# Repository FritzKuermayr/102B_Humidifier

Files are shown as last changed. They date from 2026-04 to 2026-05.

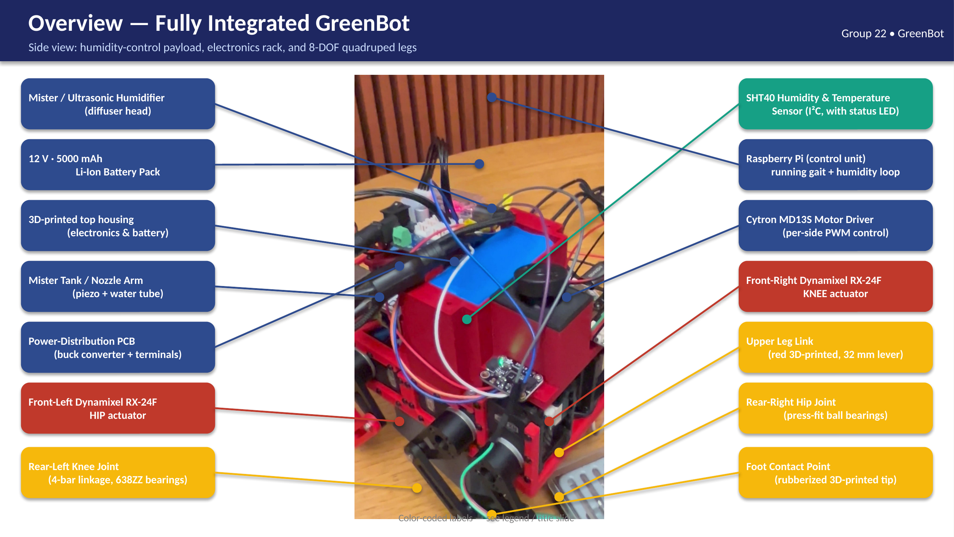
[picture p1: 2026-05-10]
docs/images/01_Overview.png

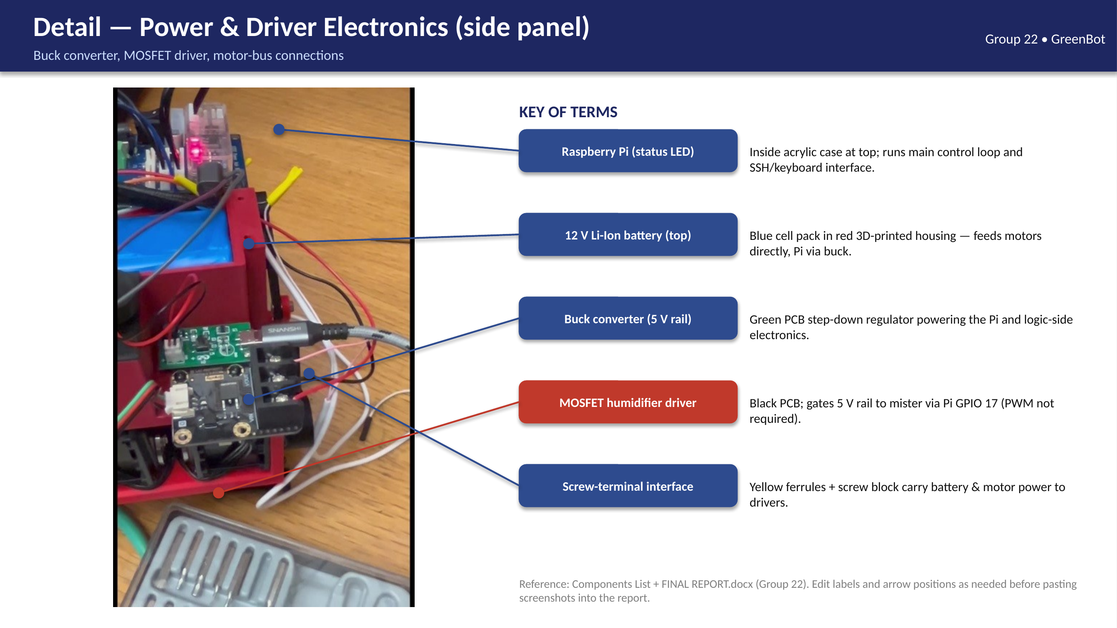
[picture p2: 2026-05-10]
docs/images/03_ElectronicsDetail.png

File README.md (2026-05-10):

# 102B — Quadruped + Humidity Control

This repository combines two subsystems used in the ME 102B project:

- **Quadruped controller** (Raspberry Pi, Dynamixel RX-24F) — keyboard-driven
  gait control over SSH.
- **Humidifier controller** (ESP32 + SHT40 + MOSFET) — closed-loop humidity
  control firmware and wiring docs.

A small set of shared Dynamixel utilities lives at the top level under
`tools/`. Course documents (reports, presentations, CAD, renders) are under
[`docs/`](docs/) — see [`docs/README.md`](docs/README.md).

## Repository Layout

```text
.
├── README.md
├── docs/                            # Reports, presentations, CAD, renders
├── software/
│   ├── humidifier/                  # ESP32 humidity control firmware + wiring
│   │   ├── esp32_humidity_control/
│   │   ├── esp32_humidity_control_switch/
│   │   ├── esp32_mosfet_test/
│   │   ├── esp32_sht40_test/
│   │   ├── wiring_humidity_control.md
│   │   └── wiring_humidity_control_switch.md
│   └── quadruped/                   # Raspberry Pi gait control
│       ├── raspi_controller/
│       │   ├── main.py
│       │   ├── g_key_leg_test.py
│       │   ├── keyboard_interface.py
│       │   └── q8gait/
│       ├── dynamixel_tools/         # Optional C utilities (DynamixelSDK)
│       ├── requirements.txt
│       └── setup_pi.sh
└── tools/                           # Standalone Dynamixel test scripts
    ├── dynamixel_scan.py
    └── single_motor_test.py
```

---

## Humidifier (ESP32)

Arduino sketches for a humidity controller using an SHT40 sensor and a
MOSFET-switched humidifier output. Open the `.ino` files with the Arduino
IDE / arduino-cli.

- `software/humidifier/esp32_humidity_control/` — closed-loop control
- `software/humidifier/esp32_humidity_control_switch/` — switch-driven variant
- `software/humidifier/esp32_mosfet_test/` — MOSFET output bring-up
- `software/humidifier/esp32_sht40_test/` — SHT40 sensor bring-up

Wiring is documented in
[`software/humidifier/wiring_humidity_control.md`](software/humidifier/wiring_humidity_control.md)
and
[`software/humidifier/wiring_humidity_control_switch.md`](software/humidifier/wiring_humidity_control_switch.md).

---

## Quadruped (Raspberry Pi)

Keyboard-driven control software for the quadruped, run directly on the Pi
over SSH.

- Pi and laptop on the same Wi-Fi network (no hotspot).
- Code on the Pi in `~/102B_Humidifier`.
- Movement: `h/j/k/l` (arrow keys as fallback).
- Default Dynamixel port `/dev/ttyUSB0`, baudrate `1000000`.
- Motors: Dynamixel RX-24F, protocol `1.0`.

### Prepare the Raspberry Pi

1. Flash Raspberry Pi OS to the microSD card.
2. Enable SSH during flashing or afterwards.
3. Connect the Pi to the regular Wi-Fi network.
4. Find the Pi's IP address: `hostname -I` — or `ssh pi@raspberrypi.local`.

### Install on the Pi

```bash
cd ~
git clone https://github.com/FritzKuermayr/102B_Humidifier.git
cd ~/102B_Humidifier
chmod +x software/quadruped/setup_pi.sh
./software/quadruped/setup_pi.sh
```

Update an existing checkout:

```bash
cd ~/102B_Humidifier
git pull origin main
```

Plug in the Dynamixel USB adapter and check it:

```bash
ls /dev/ttyUSB* /dev/ttyACM*
sudo chmod a+rw /dev/ttyUSB0   # if needed
```

### Python Dependencies

`software/quadruped/setup_pi.sh` handles installation. To reinstall:

```bash
cd ~/102B_Humidifier
source .venv/bin/activate
python -m pip install -r software/quadruped/requirements.txt
```

### Start Keyboard Control

Place the robot on a stand for the first test.

```bash
cd ~/102B_Humidifier
source .venv/bin/activate
python software/quadruped/raspi_controller/main.py \
    --port /dev/ttyUSB0 --gait TROT_LOW --torque-limit 400
```

Keys:

```text
k      walk forward
j      walk backward
h      turn left
l      turn right
Space  stop and hold neutral stance
s      stop and hold neutral stance
q      quit safely and disable torque
```

Arrow keys also work if the terminal passes them through:

```text
↑  forward    ↓  backward    ←  turn left    →  turn right
```

If the motors react too weakly on the stand, increase the torque limit:

```bash
python software/quadruped/raspi_controller/main.py \
    --port /dev/ttyUSB0 --gait TROT_LOW --torque-limit 500
```

Alternative gaits:

```bash
python software/quadruped/raspi_controller/main.py --port /dev/ttyUSB0 --gait WALK --torque-limit 500
python software/quadruped/raspi_controller/main.py --port /dev/ttyUSB0 --gait TROT --torque-limit 500
```

### Single-Leg Test

Moves only the front-left leg slightly away from neutral and back. For motor
and mapping checks only.

```bash
cd ~/102B_Humidifier
source .venv/bin/activate
python software/quadruped/raspi_controller/g_key_leg_test.py --port /dev/ttyUSB0
```

Keys: `g` to twitch the front-left leg, `q` to quit.

Mapping:

```text
FL_q1 = Motor ID 1
Neutral = 150 deg
Test movement = 165 deg for 0.35 s, then back to 150 deg
```

### Important Checks

- Motor IDs and ordering: [`software/quadruped/raspi_controller/q8gait/config_rx24f.py`](software/quadruped/raspi_controller/q8gait/config_rx24f.py).
- On startup, `main.py` moves all motors to neutral.
- On exit (`q` or `Ctrl+C`) torque is disabled.
- Always put the robot on a stand before the first motion test.
- Missing `dynamixel_sdk`: `python -m pip install -r software/quadruped/requirements.txt`.
- `/dev/ttyUSB0` not accessible: check the USB adapter, run
  `sudo chmod a+rw /dev/ttyUSB0`.

---

## Standalone Dynamixel Tools

Quick utilities under `tools/`:

- [`tools/dynamixel_scan.py`](tools/dynamixel_scan.py) — scan the bus for connected motors.
- [`tools/single_motor_test.py`](tools/single_motor_test.py) — gentle wobble test for a single motor.

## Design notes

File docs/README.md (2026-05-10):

# Project Documents — ME 102B Team 22

Course documents, reports, presentations, CAD, and renders for the ME 102B
Greenhouse-Bot project.

Videos (`.MOV`, `.mp4`) are excluded — they exceed GitHub's 100 MB per-file
limit. They live locally in the team archive.

## Contents

### `reports/`
- `FINAL REPORT me102b greenhousebot.docx` — final written report
- `FINAL_REPORT_with_labels.docx` — final report with labeled figures
- `P1 and P2 Assignment.docx` — P1/P2 assignment write-up
- `P1P2 Completed Merged.pdf` — merged P1+P2 submission
- `P3.docx` — P3 write-up
- `p4b.docx` — P4b write-up
- `P5.docx` — P5 write-up
- `cartoon (if needed again).docx` — optional cartoon storyboard

### `presentations/`
- `P1P2 PPT ME102B.pptx` — P1/P2 deck
- `P4 PPT ME102B.pptx` — P4 deck
- `GreenBot_Labeled.pptx` — labeled GreenBot deck
- `P1-P2-Teaming-And-Pitch.pdf` — teaming/pitch reference

### `diagrams/`
- `FINAL_StateDiagrams.pdf` — final state diagrams

### `cad/`
Mechanical CAD (STL for printing, STEP/STP for editing):
- `Battery-Holder.stp`
- `Controller_Holder.stl` / `.stp`
- `ESP platform.stl` / `.step`
- `Lid.stl` / `.step` and `Lidv8.stl`
- `Motor_37D.stl`
- `Upper_part.stp`

### `images/`
Labeled renders of the final assembly:
- `00_Title.png` — title image
- `01_Overview.png` — full overview
- `02_TopDetail.png` — top-side detail
- `03_ElectronicsDetail.png` — electronics detail

### `misc/`
- `102 B Team 22 Pugh Matrix.xlsx` — Pugh matrix
- `Components List.docx` — bill of materials / parts list

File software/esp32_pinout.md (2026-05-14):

# ESP32 Feather V2 — Pin Connections

Compact reference: which Feather pin connects to what. No wire colors —
those are in [`wiring_map_esp32.md`](wiring_map_esp32.md) and the
per-sketch wiring docs.

## Connections

| Feather V2 pin | Connected to |
|---|---|
| `3V` | MOSFET VCC, SHT40 VCC |
| `GND` (left) | MOSFET GND, Switch GND* |
| `GND` (right) | SHT40 GND |
| `27` | MOSFET SIG |
| `33` | Switch input* |
| `SDA` (= GPIO22)  | SHT40 SDA |
| `SCL` (= GPIO20)  | SHT40 SCL |

\* Only used by `esp32_humidity_control_switch.ino`. Switch GND shares
the same physical `GND (left)` pin as the MOSFET GND.

## External supply for the mister

Independent from the Feather; only the MOSFET output drives the mister.

| External rail | Connected to |
|---|---|
| Supply +V | MOSFET VIN (screw terminal) |
| Supply GND | MOSFET GND (screw terminal), Feather GND  |
| MOSFET VOUT | Mister + |
| Supply GND | Mister − |

The external supply GND **must** be tied to the Feather GND or the
MOSFET gate driver will not have a stable reference.

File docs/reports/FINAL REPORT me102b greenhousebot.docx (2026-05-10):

Final Report/ Manual
Group 22
Team Members: Bader AlKhawashki, Fritz Kuermayr, Salvador Gonzalez, Arunima Basu

Compile a “Manual” for your fully integrated device, such that another engineer could replicate, and even iterate upon, your project.

Opportunity:

For farmers/gardeners who own greenhouses, it’s a robot that detects local humidity within a greenhouse, and if it falls below a certain threshold (detected using analog and digital sensors), the robot humidifies the area using water mist and moves around the greenhouse to ensure proper humidification of the entire area.

High-level strategy:
Our GreenBot continuously monitors key greenhouse humidity conditions. When values drift outside target ranges, it automatically triggers the correct response (humidification).

Discussion of Initial and achieved specifications:

Discuss/compare your initial desired functionality to your achieved

specifications (e.g., we wanted to drive at least 1 foot per second and achieved a maximum speed

of 0.95 feet per second).

- A photo showing the integrated physical device, fully assembled and with labels showing where

actuators and sensors are located and highlighting any moving parts/joints. You can include a

couple views to show key subsystems as needed. Think of this diagram as a “key” of terms that

you can use in your description (e.g., “the wheel transmission...” highlight in the image what this

means to you).

Discussion of function-critical decisions and calculations.

1. Mass and Load Estimations

The total mass of the quadruped robot is estimated at approximately 2 kg, which is derived

from the main components. The eight Dynamixel RX-24F actuators contribute roughly 0.66

kg. The Raspberry Pi, OpenBCI Cyton board, and other electronics add about 0.1 kg,

and the 12 V 5000 mAh battery weighs approximately 0.35 kg. The structural components,

including the 3D-printed chassis and legs, are estimated at 0.5 kg, while the active water

payload adds about 0.3 kg.

Consequently, the total weight force acting on the robot’s center of mass is approximately

20 N. During locomotion, it is assumed as a worst-case scenario that only two legs support

the entire weight of the robot during parts of the gait cycle. Therefore, a single active leg

must support roughly 10 N of vertical static load.

2. Actuator Torque Analysis

The worst-case mechanical stress on the transmission occurs when the leg is fully extended

outward. This configuration creates the largest lever arm relative to the motor axis.

• Lever Arm: The leg length is 32 mm (0.032 m).

• Maximum Torque: The 10 N vertical load produces a resultant worst-case torque

at the motor of roughly 0.31 Nm.

The Dynamixel RX-24F actuator specified for the joints possesses a maximum stall torque

of approximately 2.6 Nm at 12 V. Because the estimated required torque of 0.31 Nm is

significantly lower than the maximum capability of the actuator, the design features a large

safety margin.

3. Bearing Load Standards (ABMA)

The primary load on the robot leg acts through the structure as a lever, transmitting forces

directly into the joints and bearings. The leg assembly utilizes 16 press-fit ball bearings to

support the rotational joints.

To verify the reliability of the transmission, the bearing loads were evaluated using American Bearing Manufacturers Association (ABMA) standards for deep-groove ball bearings.

The ABMA standard defines the effective combined bearing load using the following relationship:

Fe = (Xi· V · Fr) + (Yi· Fa)

Where:

• Fr is the radial load acting on the bearing

• Fa is the axial load

• V is a rotation factor (V = 1 when the inner ring rotates)

• Xi and Yi are radial and thrust load factors defined by the ABMA standard

In this design, the planar linkage introduces negligible axial load, therefore:

Fa = 0

The static load on a single leg is approximately 10 N. To account for dynamic walking

impacts and shocks, a conservative dynamic factor of 3 is applied. This results in a maximum

radial load of:

Fr = 30 N

Because Fa/C0 is below the ABMA limit value e, the standard coefficients are:

• Xi = 1.00

• Yi = 0

Substituting into the ABMA equation:

Fe = (1.00 · 1 · 30 N) + (0 · 0)

Fe = 30 N

Therefore, the effective bearing load is approximately 30 N in the worst-case dynamic

condition where all force is assumed to act on a single bearing.

This value remains significantly lower than the rated load capacity of standard miniature

deep-groove ball bearings such as the 638ZZ, confirming that the bearing operates safely

within its mechanical limits according to ABMA guidelines.

4. 3D-Printed Housing Tolerance Standards (ANSI)

The 16 ball bearings must be press-fit into the 3D-printed plastic upper and lower legs.

To achieve proper alignment without compromising the structural integrity of the additive

manufacturing layers, the interface relies on American National Standards Institute (ANSI)

limits and fits.

The theoretical CAD geometry was established around an ANSI H7/k6 locational transition fit. This standardized fit is an ideal compromise between clearance and interference

for accurate location.

However, standard locational interference fits (such as H7/p6) are designed for rigid

steel components and would cause the 3D-printed plastic to yield or delaminate under high

internal bore pressure. Therefore, the upper and lower fundamental deviations of the H7/k6

specification were adopted as a baseline, but light physical dimensional offsets were applied

during slicing to compensate for polymer creep and FDM resolution, ensuring a secure fit

that adheres to ANSI principles adapted for plastic housings.

State Diagrams:

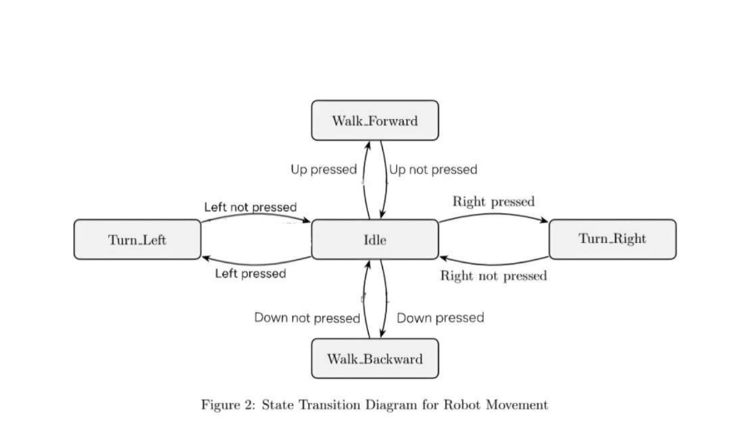
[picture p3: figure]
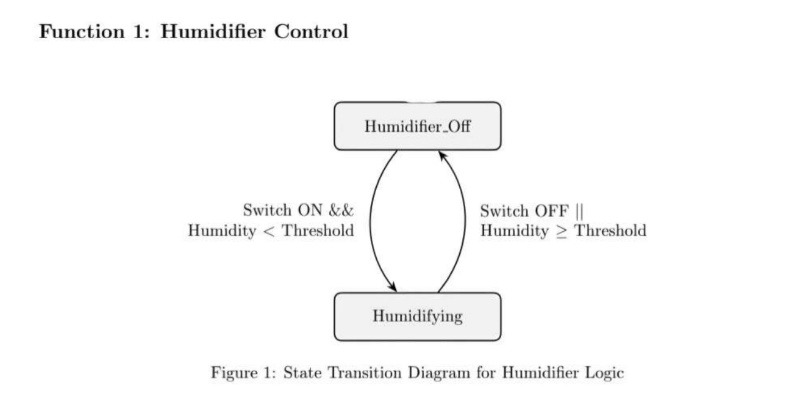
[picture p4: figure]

Reflection:
We recommend students buy spare parts in case of any issues, as one of our electronic parts had short-circuited; thankfully, we were able to fix the issue quickly using soldering, and all project deliverables were completed.

APPENDIX

o Complete Bill of Materials:

Section | Item | Qty | Cost/part (USD) | Subtotal
Upper Part | Humidity sensor | 1 | $0 | $0
Upper Part | Microcontroller (ESP32 Feather V2) | 1 | $0 | $0
Upper Part | Mister (pump + nozzle) | 1 | $10 | 10
Upper Part | Cables | 30 | $0 | $0
Upper Part | 3D-Printed Tank + Platform | 1 | $2 | $2
Upper Part | 3D Printed LED | 1 | $1 | $1
Lower Part | Upper legs (3D-printed) | 8 | $0.5 | $4
Lower Part | Lower legs (3D-printed) | 8 | $0.5 | $4
Lower Part | Ball bearings | 16 | $15 | $15
Lower Part | Chassis (3D-printed) | 1 | $5 | $5
Lower Part | Distance holder M2.5 (20 mm) | 6 | $0.15 | $1
Lower Part | Distance holder M2.5 (10 mm) | 6 | $0.15 | $1
Lower Part | Upper chassis (3-part print) | 1 | $2 | $2
Lower Part | Battery holder (3D-printed) | 1 | $1 | $1
Lower Part | Motor controller holder (3D-printed) | 1 | $1 | $1
Lower Part | Dynamixel RX-24F actuators | 8 | $0 | $0
Lower Part | 12V 5000mAh battery | 2 | $30 | $60
Lower Part | Raspberry Pi 4 | 1 | $75 | $75
Lower Part | Roboteck K4P | 9 | $20 | $180
Lower Part | USB-C to USB-B cable | 1 | $5 | $5
Lower Part | Diatone Mamba Micro 2A BEC | 1 | $4 | $4
Lower Part | U2D2 (USB-to-Serial) | 1 | $35 | $35
Lower Part | Arduino USB dongle | 1 | $10 | $10
Lower Part | Screws & Nuts | 20 | $5 | $5
Upper part | Washers | 10 | $5 | $5
Upper part | Fasteners | 10 | $0 | $0
Upper part | Gaskets | 10 | $0.5 | $5
Upper part | MOSFET | 1 | $15 | $15

o Images of the CAD, showing mechanical transmission elements.

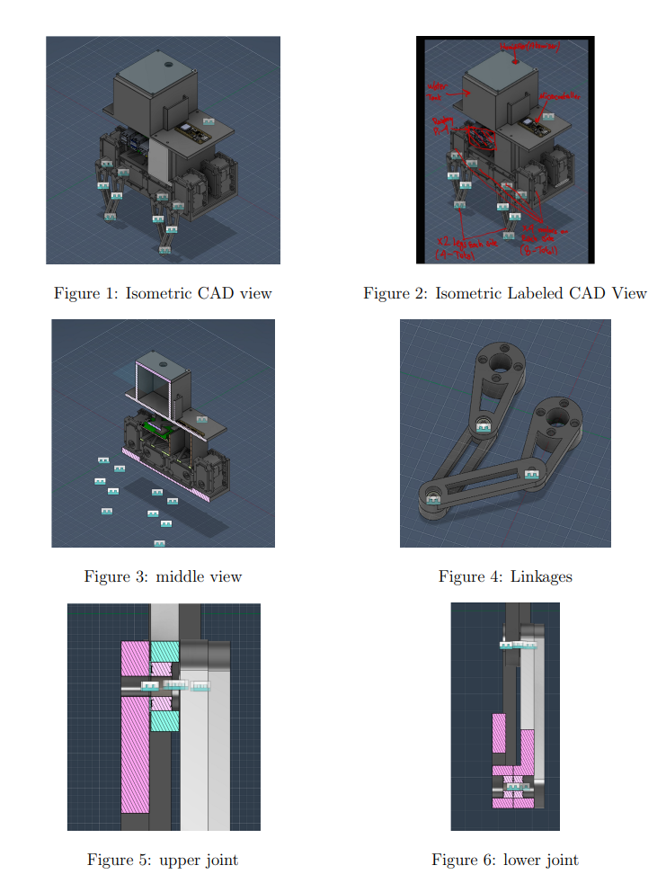
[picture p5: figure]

o Screen shots of your entire code, showing your event-driven program (most updated.)

Humidity Control Code:

1 from __future__ import annotations

2

3 import threading

4 import time

5 from dataclasses import dataclass

6 from typing import Optional

7

8 # Standard humidity - control c on fi gu ra ti on .

9 HUMIDITY_THRESHOLD = 45.0

10 SENSOR_POLL_INTERVAL_SEC = 2.0

11 HUMIDIFIER_GPIO = 17

12 ENABLE_SWITCH_GPIO = 27

13 I2C_SENSOR = " SHT40 on Raspberry Pi I2C1 : GPIO2 / SDA1 and GPIO3 / SCL1 "

14 SWITCH_DEBOUNCE_MS = 50

15

16

17 @dataclass ( frozen = True )

18 class HumidityControlConfig :

19 humidity_threshold : float = HUMIDITY_THRESHOLD

20 sensor_poll_interval_sec : float = SENSOR_POLL_INTERVAL_SEC

21 humidifier_gpio : int = HUMIDIFIER_GPIO

22 enable_switch_gpio : int = ENABLE_SWITCH_GPIO

23 switch_debounce_ms : int = SWITCH_DEBOUNCE_MS

24

25

26 class HumidityController :

27 """

28 Non - blocking SHT40 humidity controller for a MOSFET - switched humidifier .

29

30 The control loop runs in its own daemon thread . Any sensor read error or

31 disabled enable switch forces the humidifier GPIO low .

32 """

33

34 def __init__ ( self , config : Optional [ HumidityControlConfig ] = None ) -> None :

35 self . config = config or HumidityControlConfig ()

36 self . _stop_event = threading . Event ()

37 self . _thread : Optional [ threading . Thread ] = None

38 self . _humidifier_output = None

39 self . _enable_switch = None

40 self . _sensor = None

41

42 def start ( self ) -> None :

43 if self . _thread is not None :

44 return

45

46 try :

47 self . _setup_gpio ()

48 self . _humidifier_off ()

49 except Exception :

50 self . _humidifier_off ()

51 self . _close_gpio ()

52 raise

53

54 self . _thread = threading . Thread (

55 target = self . _loop , name =" humidity - control ", daemon = True

56 )

57 self . _thread . start ()

58 print (

59 "[ humidity ] started "

60 f" threshold ={ self . config . humidity_threshold :.1 f}% "

61 f" poll ={ self . config . sensor_poll_interval_sec :.1 f}s"

62 )

63

64 def stop ( self ) -> None :

65 self . _stop_event . set ()

66 if self . _thread is not None :

67 self . _thread . join (

68 timeout = max (1.0 , self . config . sensor_poll_interval_sec + 0.5)

69 )

70 self . _thread = None

71

72 self . _humidifier_off ()

73 self . _close_gpio ()

74 print ("[ humidity ] stopped ")

75

76 # STATE MACHINE DRIVER :

77 # Periodically runs the humidity - control state machine without blocking the

78 # quadruped movement loop .

79 def _loop ( self ) -> None :

80 while not self . _stop_event . is_set () :

81 self . _control_once ()

82 self . _stop_event . wait ( self . config . sensor_poll_interval_sec )

83

84 # STATE MACHINE TRANSITION LOGIC :

85 def _control_once ( self ) -> None :

86 if not self . _switch_enabled () :

87 self . _humidifier_off ()

88 return

89

90 humidity = self . _read_humidity ()

91 if humidity is None :

92 self . _humidifier_off ()

93 return

94

95 if humidity < self . config . humidity_threshold :

96 self . _humidifier_on ()

97 else :

98 self . _humidifier_off ()

99

100 # SERVICE FUNCTION :

101 def _setup_gpio ( self ) -> None :

102 try :

103 from gpiozero import Button , DigitalOutputDevice

104 except ImportError as exc :

105 raise RuntimeError (

106 " gpiozero is required for humidity control . Run software / setup_pi .sh on the Raspberry

Pi."

107 ) from exc

108

109 self . _humidifier_output = DigitalOutputDevice (

110 self . config . humidifier_gpio ,

111 active_high = True ,

112 initial_value = False ,

113 )

114 self . _enable_switch = Button (

115 self . config . enable_switch_gpio ,

116 pull_up = True ,

117 bounce_time = self . config . switch_debounce_ms / 1000.0 ,

118 )

119

120 # SERVICE FUNCTION :

121 def _close_gpio ( self ) -> None :

122 for device in ( self . _humidifier_output , self . _enable_switch ):

123 if device is not None :

124 device . close ()

125 self . _humidifier_output = None

126 self . _enable_switch = None

127

128 # EVENT CHECKER :

129 def _switch_enabled ( self ) -> bool :

130 return bool ( self . _enable_switch is not None and self . _enable_switch . is_pressed )

131

132 # SERVICE FUNCTION :

133 def _humidifier_on ( self ) -> None :

134 if self . _humidifier_output is not None :

135 self . _humidifier_output . on ()

136

137 # SERVICE FUNCTION :

138 def _humidifier_off ( self ) -> None :

139 if self . _humidifier_output is not None :

140 self . _humidifier_output . off ()

141

142 # EVENT CHECKER :

143 def _read_humidity ( self ) -> Optional [ float ]:

144 sensor = self . _get_sensor ()

145 if sensor is None :

146 return None

147

148 try :

149 _temperature_c , relative_humidity = sensor . measurements

150 except Exception as exc :

151 print (f"[ humidity ] sensor read failed ; humidifier off : { exc}")

152 self . _sensor = None

153 return None

154

155 return float ( relative_humidity )

156

157 # SERVICE FUNCTION :

158 def _get_sensor ( self ):

159 if self . _sensor is not None :

160 return self . _sensor

161

162 try :

163 import adafruit_sht4x

164 import board

165

166 self . _sensor = adafruit_sht4x . SHT4x ( board . I2C () )

167 except Exception as exc :

168 print (f"[ humidity ] sensor init failed ; humidifier off : { exc}")

169 self . _sensor = None

170

171 return self . _sensor

Motion Control Code:
1 from __future__ import annotations

2

3 import time

4 from typing import Optional

5

6 from . gait_manager import GAITS , GaitManager

7 from . kinematics_solver import k_solver

8 from . robot import Robot

9

10 COMMAND_TO_DIRECTION = {

11 # MOVEMENT STATE MACHINE STATES :

12 # " stop " is the IDLE state . The other commands are active movement states .

13 " forward ": "f",

14 " backward ": "b",

15 " turn_left ": "l",

16 " turn_right ": "r",

17 " stop ": None ,

18 }

19

20

21 class MotionRunner :

22 def __init__ (

23 self ,

24 robot : Robot ,

25 leg_solver : k_solver ,

26 gait_name : str = " TROT_LOW ",

27 hz : int = 50 ,

28 neutral_center_deg : float = 150.0 ,

29 torque_limit : int = 600 ,

30 moving_speed : int = 0,

31 ) -> None :

32 self . robot = robot

33 self . leg = leg_solver

34 self . hz = hz

35 self . dt = 1.0 / hz

36 self . neutral_center_deg = neutral_center_deg

37 self . torque_limit = torque_limit

38 self . moving_speed = moving_speed

39 self . gait_manager = GaitManager ( self . leg , GAITS )

40 self . current_command = " stop "

41

42 if not self . gait_manager . load_gait ( gait_name ):

43 raise RuntimeError (f" Failed to load gait { gait_name }")

44

45 _ , x0 , y0 , *_ = GAITS [ gait_name ]

46 q1n , q2n , ok = self . leg . ik_solve (x0 , y0 , True , 3)

47 if not ok :

48 raise RuntimeError ("IK failed for neutral pose .")

49 self . q_neutral = [ q1n , q2n , q1n , q2n , q1n , q2n , q1n , q2n ]

50

51 # SERVICE FUNCTION :

52 def move_to_neutral ( self , seconds : float = 1.0) -> None :

53 command = [ self . neutral_center_deg ] * 8

54 for _ in range (max (1 , int ( seconds * self . hz ))):

55 self . robot . write_positions_deg ( command )

56 time . sleep ( self . dt )

57

58 # STATE MACHINE TRANSITION LOGIC :

59 def set_command ( self , command : Optional [ str ]) -> None :

60 if command is None or command == self . current_command :

61 return

62

63 if command == " quit ":

64 raise KeyboardInterrupt

65

66 direction = COMMAND_TO_DIRECTION . get ( command )

67 if direction is None :

68 self . gait_manager . stop ()

69 self . current_command = " stop "

70 return

71

72 self . robot . set_torque_limit_all ( self . torque_limit )

73 self . robot . set_moving_speed_all ( self . moving_speed )

74

75 if not self . gait_manager . start_movement ( direction ):

76 self . gait_manager . stop ()

77 self . current_command = " stop "

78 return

79

80 self . current_command = command

81

82 # SERVICE FUNCTION :

83 def tick ( self ) -> None :

84 q_abs = self . gait_manager . tick ()

85 if q_abs is None :

86 self . robot . write_positions_deg ([ self . neutral_center_deg ] * 8)

87 return

88

89 self . robot . write_positions_deg ( self . _recenter_to_neutral ( q_abs ))

90

91 # STATE MACHINE DRIVER :

92 def loop_forever ( self , keyboard_interface ) -> None :

93 next_tick = time . perf_counter ()

94 while True :

95 self . set_command ( keyboard_interface . poll () )

96

97 now = time . perf_counter ()

98 if now >= next_tick :

99 self . tick ()

100 next_tick += self . dt

101 else :

102 time . sleep ( max (0.0 , next_tick - now ))

103

104 # SERVICE FUNCTION :

105 def _recenter_to_neutral ( self , q_abs_8 : list [ float ]) -> list [ float ]:

106 return [

107 self . neutral_center_deg + ( q_abs_8 [i] - self . q_neutral [i ])

108 for i in range (8)

109 ]

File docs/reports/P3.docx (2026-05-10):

Deliverable 1: Isometric screen shot of your design with labels for understanding, and any sub-

assembly close-ups or cross-sections to show how it works should also be included as needed.

Components List:
Upper Part:

- Humidity sensor - https://projecthub.arduino.cc/rudraksh2008/temperature-and-humidity-sensor-with-arduino-1d52a6
- Microcontroller .- Adafruit V2 ESP 32 - https://github.com/adafruit/Adafruit_CAD_Parts/tree/main/5400%20ESP32%20Feather%20V2
- Mister (https://www.amazon.com/MTDELE-Humidifier-Atomization-Compatible-Incubation/dp/B0DC73SF6L?nsdOptOutParam=true) - Pump mechanism + nozzle - (Ordered)
- Cables
- 3D-Printed Tank + Platform
- 3D Printed led

Lower Part:

- 8× upper leg (3D-printed)
- 8× lower leg (3D-printed)
- 16× ball bearings (press-fit)
- 1× chassis (3D-printed)
- 6× distance holder, M2.5, 20 mm (3D-printed)
- 6× distance holder, M2.5, 10 mm (3D-printed)
- 1× upper chassis (3D-printed, 3-part print)
- 1× battery holder (3D-printed)
- 1× motor controller holder (3D-printed)
- 8× Dynamixel RX-24F robot actuators
- 1× 12 V 5000 mAh battery
- 1× Raspberry Pi 4
- 9× Roboteck K4P
- 1× USB-C to USB-B cable
- 1× Diatone Mamba Micro 2A BEC
- 1× U2D2 (USB-to-Serial)
- 1× Arduino USB dongle

Screws & Nuts

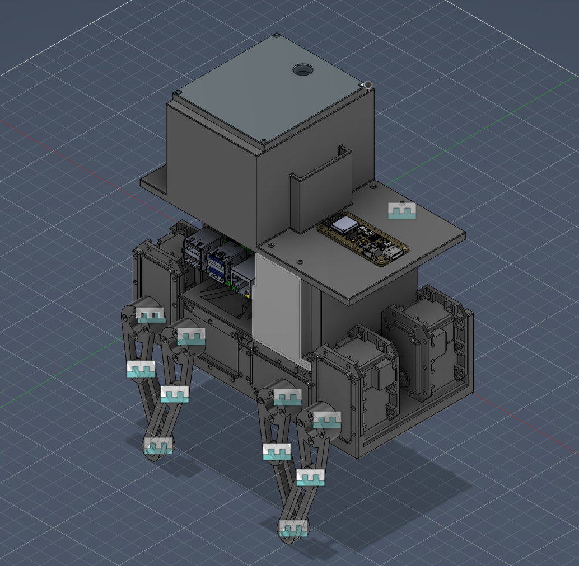
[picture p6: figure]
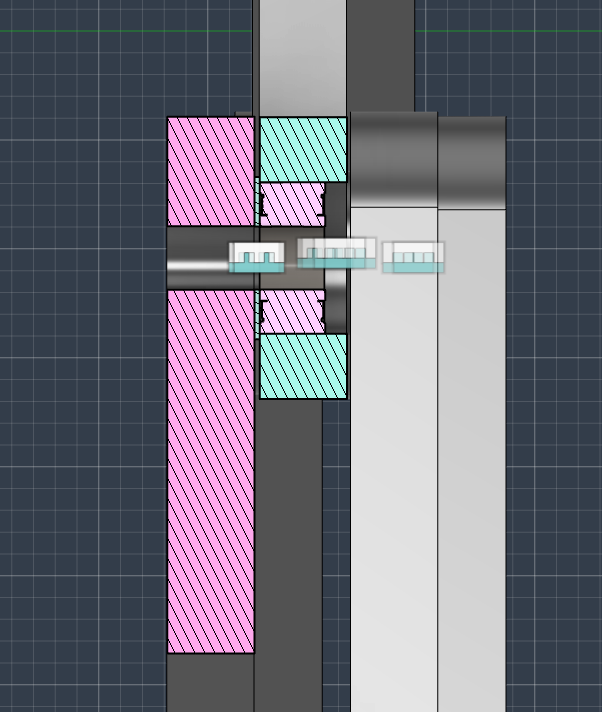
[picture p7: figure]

Upper Joint

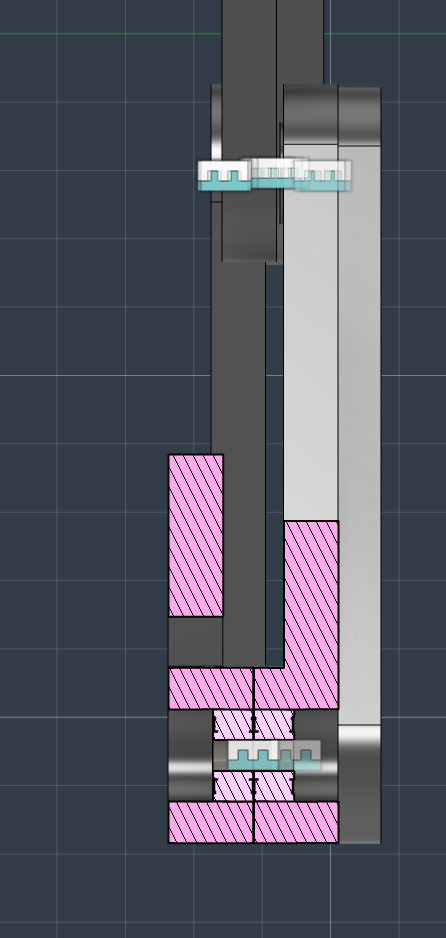
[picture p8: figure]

Lower joint

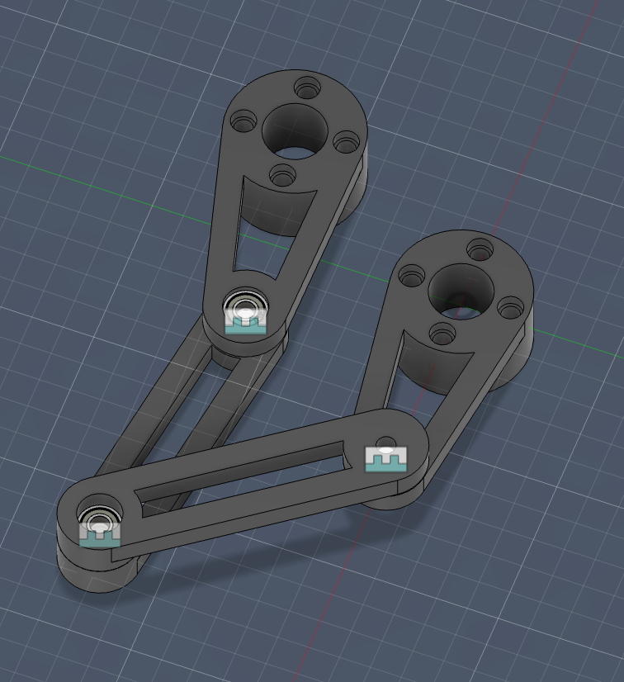
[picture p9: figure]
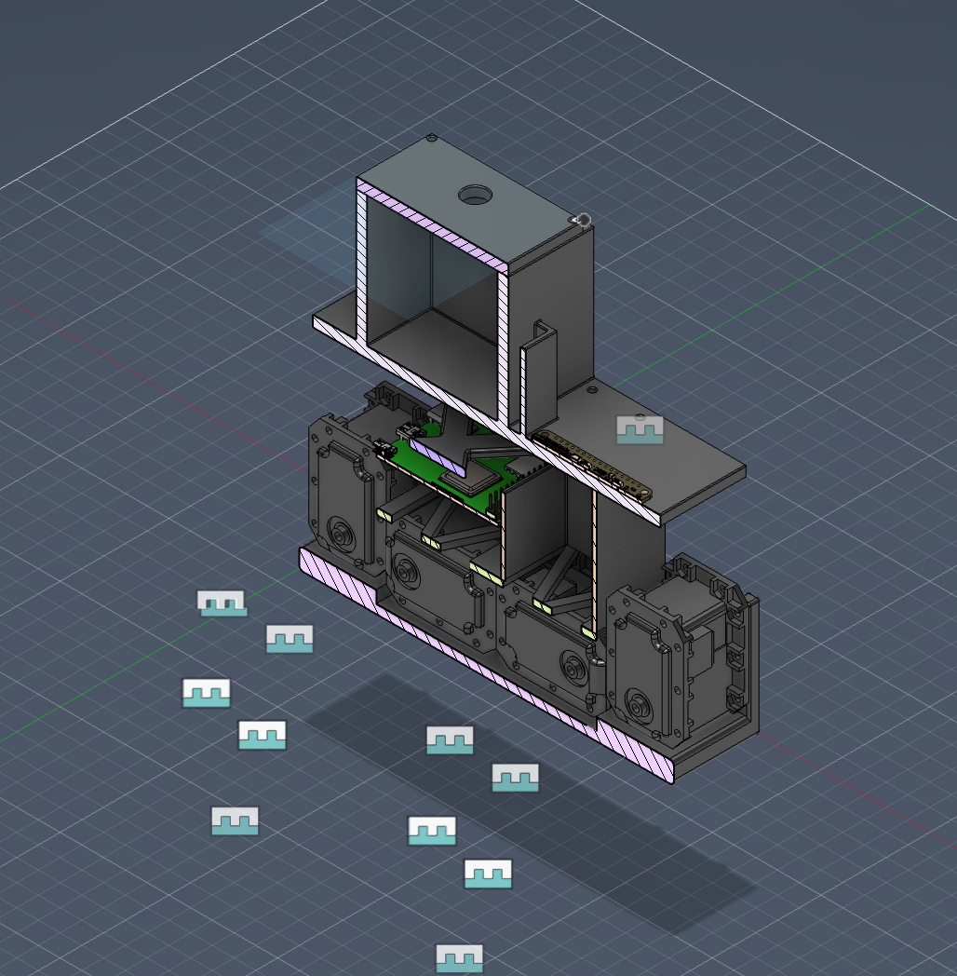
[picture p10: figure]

Cross sectional views

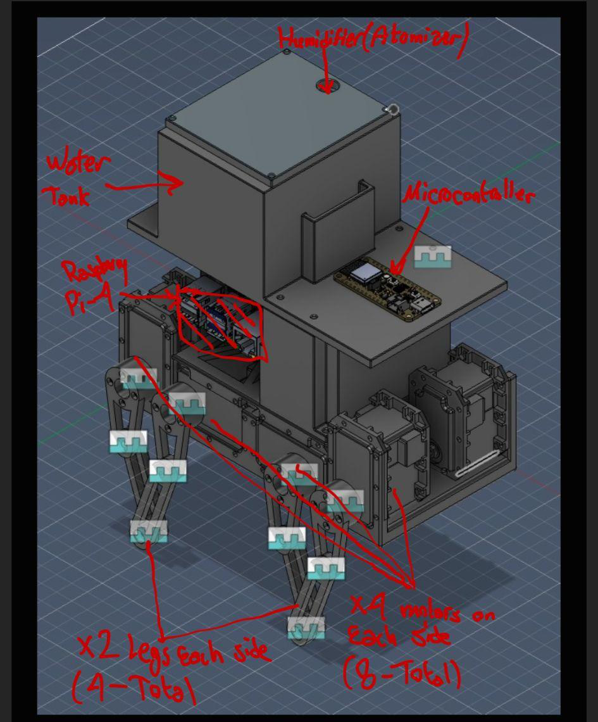
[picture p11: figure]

V2 Response

Deliverable 2: Function-Critical Calculations & Standards Integration

1. Mass and Load Estimations

The total mass of the quadruped robot is estimated at approximately 2 kg, which is derived from the main components. The eight Dynamixel RX-24F actuators contribute roughly 0.66 kg. The Raspberry Pi, OpenBCI Cyton board, and other electronics add about 0.1 kg, and the 12 V 5000 mAh battery weighs approximately 0.35 kg. The structural components, including the 3D-printed chassis and legs, are estimated at 0.5 kg, while the active water payload adds about 0.3 kg.

Consequently, the total weight force acting on the robot's center of mass is approximately 20 N. During locomotion, it is assumed as a worst-case scenario that only two legs support the entire weight of the robot during parts of the gait cycle. Therefore, a single active leg must support roughly 10 N of vertical static load.

2. Actuator Torque Analysis

The worst-case mechanical stress on the transmission occurs when the leg is fully extended outward. This configuration creates the largest lever arm relative to the motor axis.

- Lever Arm: The leg length is 32 mm (0.032 m).
- Maximum Torque: The 10 N vertical load produces a resultant worst-case torque at the motor of roughly 0.31 Nm.

The Dynamixel RX-24F actuator specified for the joints possesses a maximum stall torque of approximately 2.6 Nm at 12 V. Because the estimated required torque of 0.31 Nm is significantly lower than the maximum capability of the actuator, the design features a large safety margin.

## 3.Bearing Load Standards (ABMA)

The primary load on the robot leg acts through the structure as a lever, transmitting forces directly into the joints and bearings. The leg assembly utilizes 16 press-fit ball bearings to support the rotational joints.

To verify the reliability of the transmission, the bearing loads were evaluated using American Bearing Manufacturers Association (ABMA) standards for deep-groove ball bearings. The ABMA standard defines the effective combined bearing load using the following relationship:

Fe = (Xi · V · Fr) + (Yi · Fa)

Where:

- Fr is the radial load acting on the bearing
- Fa is the axial load
- V is a rotation factor (V = 1 when the inner ring rotates)
- Xi and Yi are radial and thrust load factors defined by the ABMA standard

In this design, the planar linkage introduces negligible axial load, therefore:

Fa = 0

The static load on a single leg is approximately 10 N. To account for dynamic walking impacts and shocks, a conservative dynamic factor of 3 is applied. This results in a maximum radial load of:

Fr = 30 N

Because Fa / C0 is below the ABMA limit value e, the standard coefficients are:

Xi = 1.00
Yi = 0

Substituting into the ABMA equation:

Fe = (1.00 · 1 · 30 N) + (0 · 0)

Fe = 30 N

Therefore, the effective bearing load is approximately 30 N in the worst-case dynamic condition where all force is assumed to act on a single bearing.

This value remains significantly lower than the rated load capacity of standard miniature deep-groove ball bearings such as the 638ZZ, confirming that the bearing operates safely within its mechanical limits according to ABMA guidelines.

Standards and Codes_v2 (1)

4. 3D-Printed Housing Tolerance Standards (ANSI)

The 16 ball bearings must be press-fit into the 3D-printed plastic upper and lower legs. To achieve proper alignment without compromising the structural integrity of the additive manufacturing layers, the interface relies on American National Standards Institute (ANSI) limits and fits.

The theoretical CAD geometry was established around an ANSI H7/k6 locational transition fit. This standardized fit is an ideal compromise between clearance and interference for accurate location. However, standard locational interference fits (such as H7/p6) are designed for rigid steel components and would cause the 3D-printed plastic to yield or delaminate under high internal bore pressure. Therefore, the upper and lower fundamental deviations of the H7/k6 specification were adopted as a baseline, but light physical dimensional offsets were applied during slicing to compensate for polymer creep and FDM resolution, ensuring a secure fit that adheres to ANSI principles adapted for plastic housings.

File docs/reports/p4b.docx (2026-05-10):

P4 Part B

Team #22

Members: Bader AlKhawashki, Arunima Basu, Fritz Kuermayr, Salvador Gonzalez

Deliverable 1: Isometric screenshot of your design with labels for understanding, and any sub-

assembly close-ups or cross-sections to show how it works should also be included as needed.

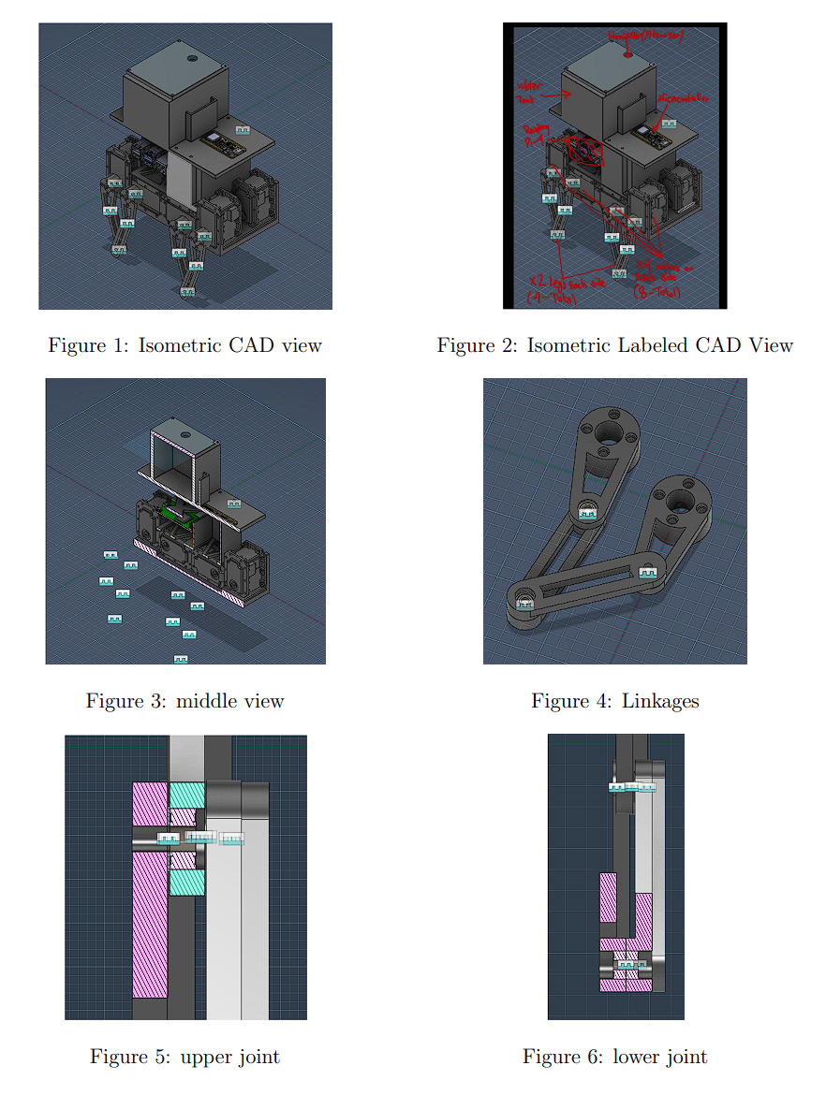
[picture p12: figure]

Deliverable 2: Updated function-critical back-of-the-envelope calculations regarding transmission design and/or bearing loads. You must include all major estimations for the design above, as taught in the class (e.g., if you have a custom gear transmission then you should compute resultant loads, if your motor has a radial load show that it doesn’t exceed the max spec of the motor, etc.). Note if you believe you do not have need to make any new updates from the calculations you made in P4, you can leave this part blank with a note “no new calculation updates needed”.

No new calculations needed

Deliverable 3:

Please briefly elaborate on at least one aspect of your machine design based on a specific Standard or Code (file linked in bCourse: Files à Project Assignment à P3). Your angle of elaboration could focus on either the specific dimensions and parts chosen for mechanical components (e.g., how did you choose the shaft and bearing for a slip fit), or meeting certain mechanical performance criteria in your back-of-the-envelope calculations (e.g., whether the load applied to the chosen bearing is within the rated effective load). Please mention which Standard or Code did you follow.

Note: We understand that some projects did not purchase components from sources providing technical specifications aligned with the related Standards and Codes. Additionally, some projects opted to machine their own parts using lower-cost or rapid-prototyping methods (e.g., laser-cutting gears from plywood, or non-standard wire rope for flexible transmissions). In such cases, or when there are no direct ways to apply Standards and Codes to your current project implementation, please include a brief comment: Explain which Standards and Codes you might need to reference if you were to further develop the project into a real product intended for mass production by using off-the-shelf components following industrial standards.

One aspect of our machine design that can be related to an engineering standard is the fit between the ball bearings and the upper and lower leg housings. In a conventionally machined design, this interface would be specified using a standard limits-and-fits system such as the ANSI system for hole and shaft fits. For example, a locational transition or light interference fit such as H7/k6 could be used as a starting point to ensure accurate bearing positioning while still allowing assembly.

In our actual prototype, however, the bearing seats are integrated into 3D-printed plastic parts rather than machined metal components. Because FDM printing does not provide the dimensional precision or surface quality required to reliably realize exact standardized fits, we did not implement the nominal ANSI fit values directly. Instead, we used the standard as a design reference: it informed the kind of fit relationship we wanted conceptually, namely a fit that locates the bearing securely without excessive interference. In practice, the final bore dimensions were adjusted empirically to account for print tolerances, layer-based anisotropy, polymer compliance, and the risk of cracking or delamination during press-fit assembly.

Deliverable 4: The complete Bill of Materials table of the required parts, listing name, quantity, cost and source links (including all small elements such as fasteners and washers).

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

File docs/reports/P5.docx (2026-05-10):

On Overleaf

P5

Team #22

Members: Bader AlKhawashki, Arunima Basu, Fritz Kuermayr, Salvador Gonzalez

https://www.overleaf.com/8726738881hrgmdpmfchhm#3d4203

Deliverable 1: A video clip of your motor(s) moving as desired. It must be driven by your microcontroller using the Arduino IDE and the motor driver you intend to use in your final project.

Deliverable 2: A state transition diagram of your machine’s behavior. Remember to follow the formatting described in lecture to show the states, event checkers, and services.

Deliverable 3: A screen shot of your state machine code written in the Arduino IDE (full code). Clearly label event checker and service functions using comments in your code.

Deliverable 4: A video clip demonstrating the full set of behaviors in Deliverable 2/3. Depict state transitions by showing the Serialprints on the screen while simultaneously showing someone triggering different events by hand with the sensors. Since it may be hard to see what’s going on in the video, a voice over will help us to assess whether you have shown all transitions and states.

Deliverable 5: Video clips of all key moving (articulated) mechanisms moving smoothly / as desired.

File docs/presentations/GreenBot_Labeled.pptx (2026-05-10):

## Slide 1

GreenBot — Integrated Device

Annotated views of actuators, sensors, joints & subsystems

MEC ENG 102B · Mechatronics Design · Spring 2026 · Group 22

Bader AlKhawashki · Fritz Kuermayr · Salvador Gonzalez · Arunima Basu

LABEL COLORS

Actuator

Sensor

Moving part / joint

Subsystem

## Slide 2

Overview — Fully Integrated GreenBot

Side view: humidity-control payload, electronics rack, and 8-DOF quadruped legs

Color-coded labels — see legend / title slide

Group 22 • GreenBot

SHT40 Humidity & Temperature
Sensor (I²C, with status LED)

Mister / Ultrasonic Humidifier
(diffuser head)

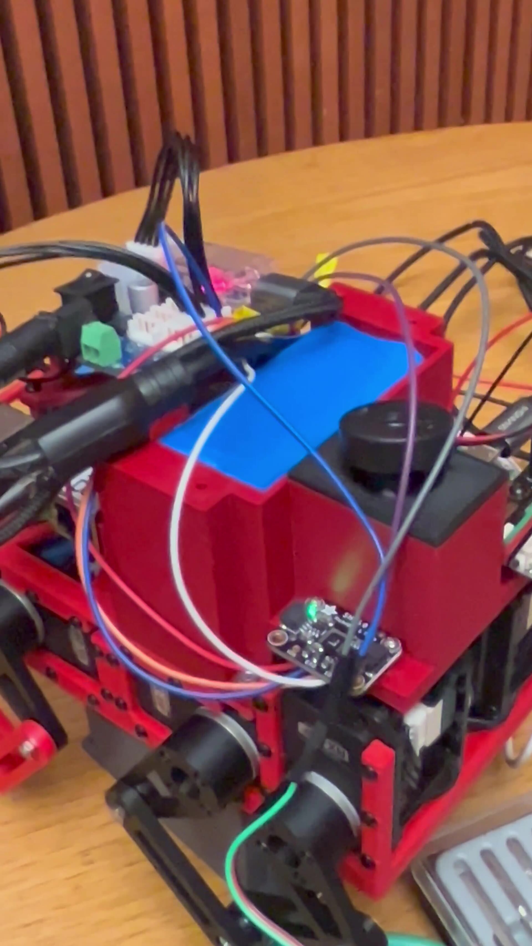
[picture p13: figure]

12 V · 5000 mAh
Li-Ion Battery Pack

Raspberry Pi (control unit)
running gait + humidity loop

3D-printed top housing
(electronics & battery)

Cytron MD13S Motor Driver
(per-side PWM control)

Mister Tank / Nozzle Arm
(piezo + water tube)

Front-Right Dynamixel RX-24F
KNEE actuator

Power-Distribution PCB
(buck converter + terminals)

Upper Leg Link
(red 3D-printed, 32 mm lever)

Front-Left Dynamixel RX-24F
HIP actuator

Rear-Right Hip Joint
(press-fit ball bearings)

Rear-Left Knee Joint
(4-bar linkage, 638ZZ bearings)

Foot Contact Point
(rubberized 3D-printed tip)

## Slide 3

Detail — Humidity Payload & Top Body

Sensor, mister diffuser, and battery housing

Group 22 • GreenBot

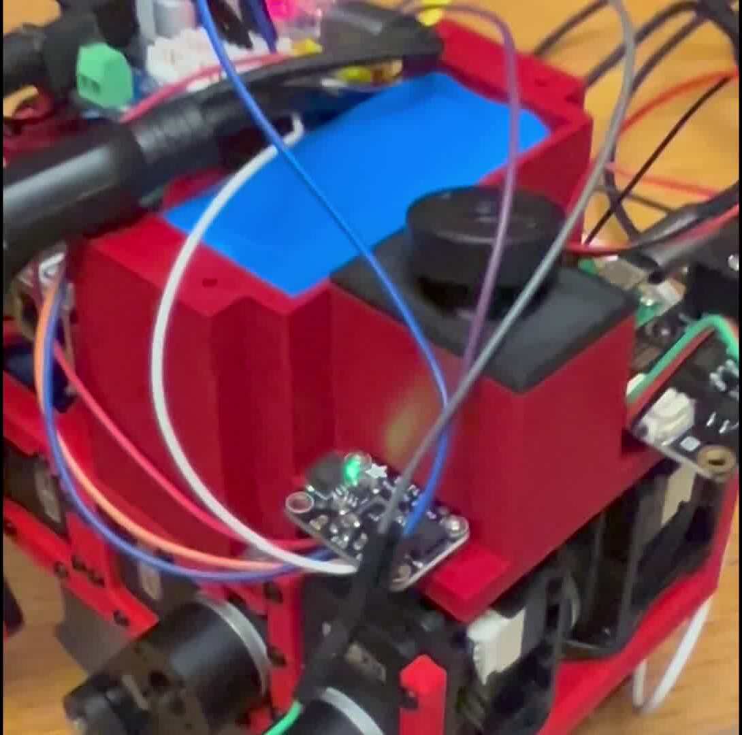
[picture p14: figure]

KEY OF TERMS

Piezoelectric ultrasonic humidifier head, MOSFET-switched on GPIO 17.

Mister diffuser

SHT40 humidity sensor

Adafruit I²C breakout (SDA = GPIO2, SCL = GPIO3); reads RH and temp at 0.5 Hz.

3D-printed top housing

FDM PETG enclosure for Pi + drivers; mounts to red lower chassis.

12 V Li-Ion battery

Visible blue cell pack; powers motor bus and 5 V rail via buck.

Mister tank arm

Bottle + silicone water tube to diffuser; held by clip on chassis.

Front Dynamixel motor

RX-24F serial-bus servo, 2.6 N·m stall, 1 Mbaud on /dev/ttyUSB0.

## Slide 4

Detail — Power & Driver Electronics (side panel)

Buck converter, MOSFET driver, motor-bus connections

KEY OF TERMS

Inside acrylic case at top; runs main control loop and SSH/keyboard interface.

Reference: Components List + FINAL REPORT.docx (Group 22). Edit labels and arrow positions as needed before pasting screenshots into the report.

Group 22 • GreenBot

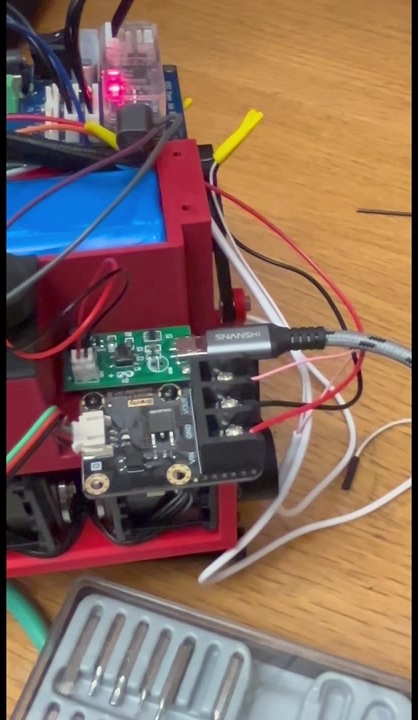
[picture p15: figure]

Raspberry Pi (status LED)

12 V Li-Ion battery (top)

Blue cell pack in red 3D-printed housing — feeds motors directly, Pi via buck.

Buck converter (5 V rail)

Green PCB step-down regulator powering the Pi and logic-side electronics.

MOSFET humidifier driver

Black PCB; gates 5 V rail to mister via Pi GPIO 17 (PWM not required).

Screw-terminal interface

Yellow ferrules + screw block carry battery & motor power to drivers.

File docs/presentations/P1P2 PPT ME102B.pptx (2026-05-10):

## GreenBot

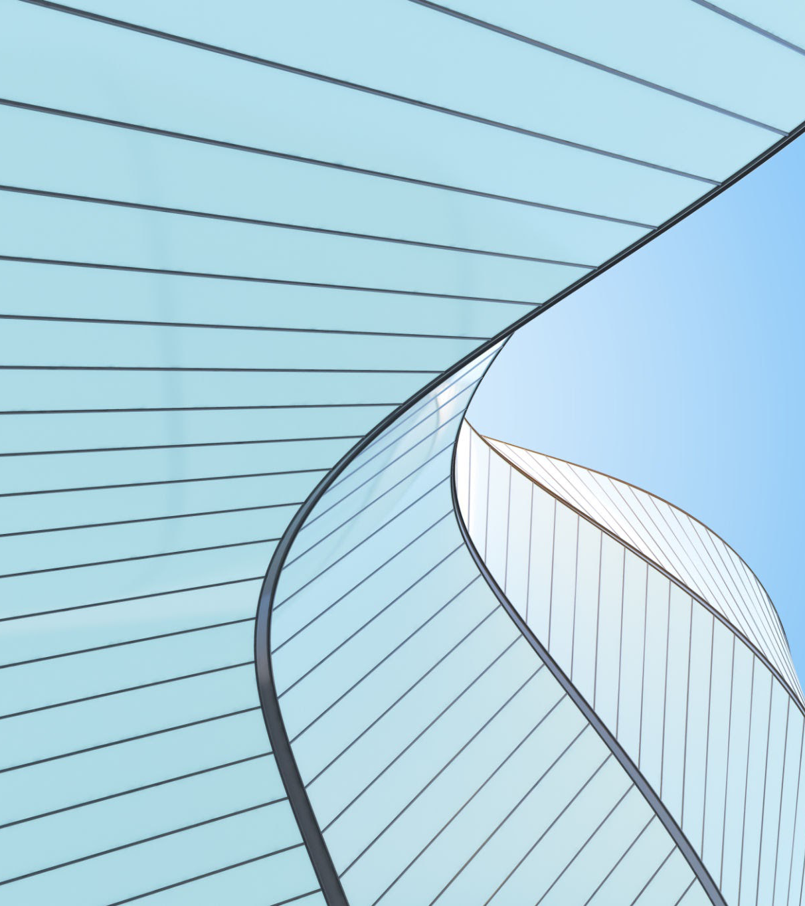
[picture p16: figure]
A close-up of a modern glass structure.

Greenhouse Robot : Mechatronics Prototype project

ME 102B
Team #22

Team Members:
Bader AlKhawashki, Arunima Basu, Fritz Kuermayr, Salvador Gonzalez

## Del. 4A

Farmers work long hours, but they cannot always be inside their greenhouses to constantly check humidity and adding nutrients to soils every set number of hours.
Even small changes in these conditions can affect plant health and crop yield.
Many existing automation systems are either too expensive or too complicated for everyday use, especially for small and medium sized farms. Because of this, farmers need a simple and affordable way to monitor and control their greenhouse environment even when they are not physically present.
Our GreenBot is designed to solve this problem by helping farmers easily manage greenhouse conditions remotely and automatically, reducing stress, saving time, and improving crop growth.

## Del. 4B

GreenBot continuously monitors key greenhouse humidity conditions. When values drift outside target ranges, it automatically triggers the correct response (humidification).

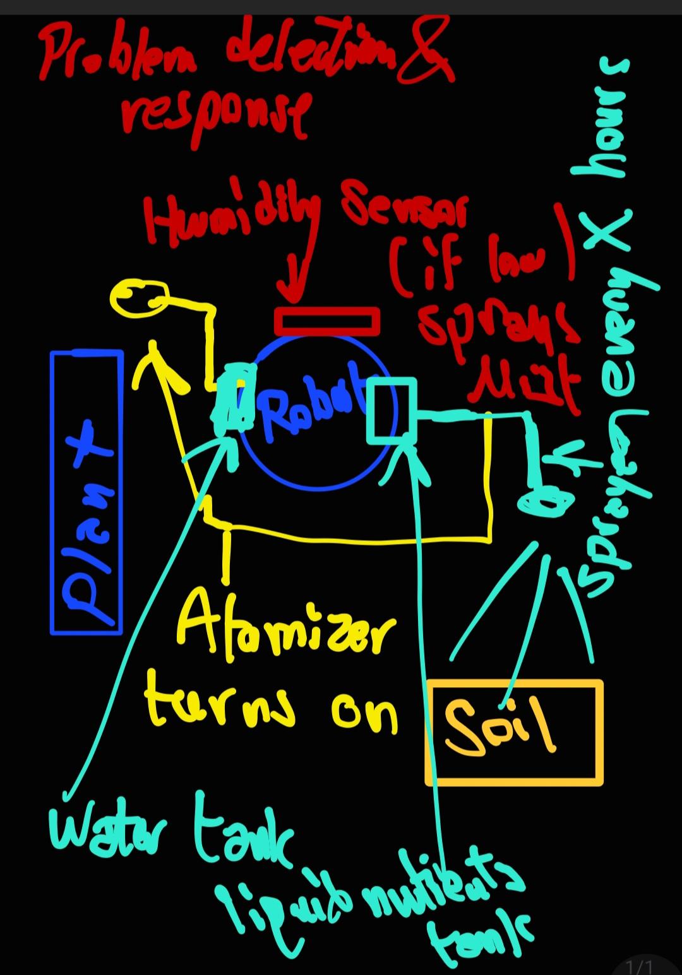
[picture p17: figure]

Figure 1: Deliverable 4.B Cartoon
* Degrees of Freedom: robot moves in any direction on the ground using motors. Sprayer can extend and retract (could be switched to static sprayer), humidity sensor stays static
** Subject to change

## Del. 4C

Key Observations
- Humidity varies across the greenhouse; it is not evenly distributed
- A stationary humidifier does not provide full coverage
- Robot movement improves humidity and liquid distribution
- Sensor placement near plant level is important
These tests confirmed that a mobile robot with automatic humidity control is a feasible and effective solution.
(* Design subject to change.)

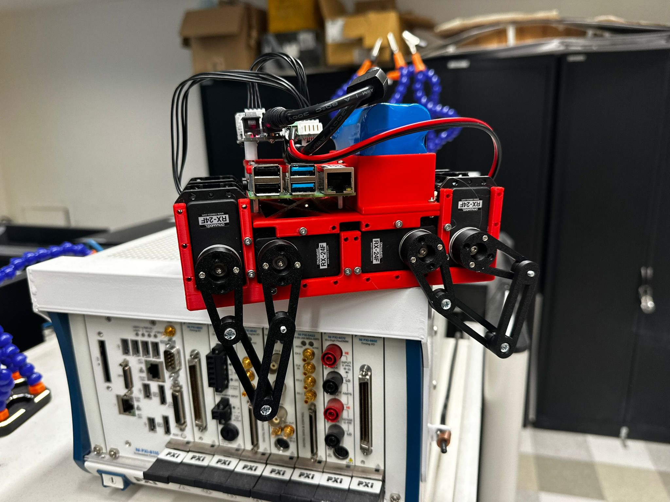
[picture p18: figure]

Figure 2: Early prototype picture

Materials Exploration & Early Prototyping
We gathered basic materials to test key subsystems of our greenhouse robot, including a humidity sensor, small humidifier module, and a 4-legged robot. We also used a spray bottle with water to represent nutrient liquid delivery.
We play-acted the robot’s behavior by manually moving the mockup through a marked greenhouse area while taking humidity readings at different locations and heights. When humidity dropped below a set threshold, we activated the humidifier to observe how quickly and how far moisture spread.

## Del 4D

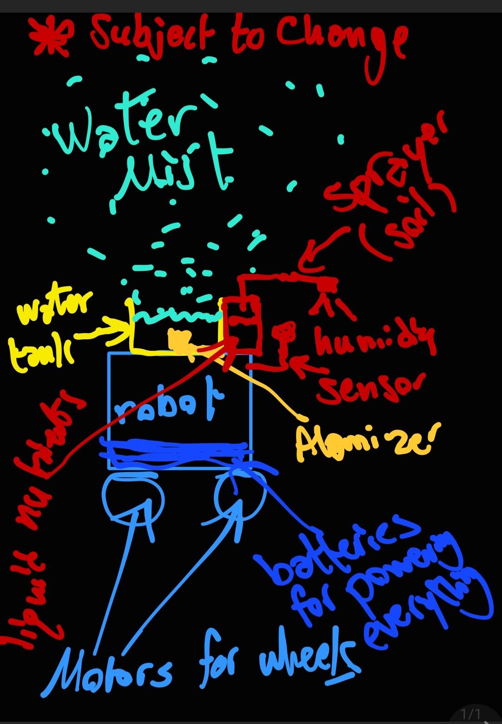
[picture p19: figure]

Figure 3: Deliverable 4.D Sketch *Subject to Change

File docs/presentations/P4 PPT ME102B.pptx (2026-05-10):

## GreenBot

Quadruped Greenhouse Humidity Monitoring & Misting Robot

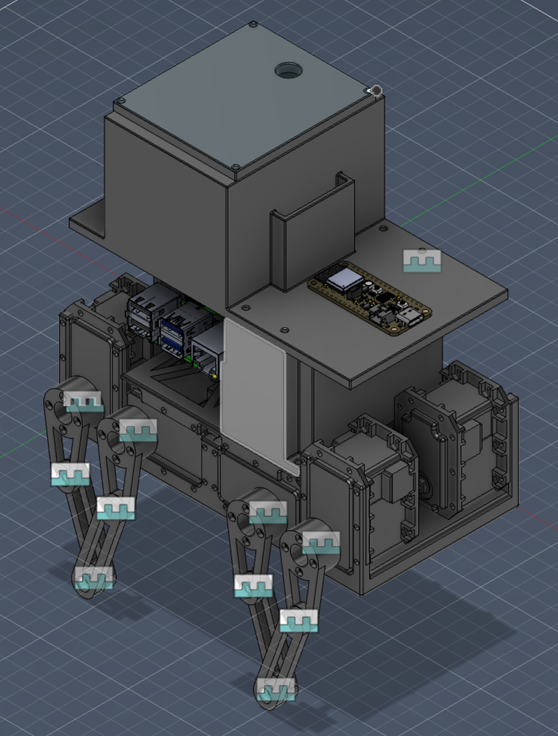
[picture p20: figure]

Team Members:
Bader AlKhawashki, Arunima Basu, Fritz Kuermayr, Salvador Gonzalez

The goal of this project is to create a simple and affordable greenhouse automation system for small and medium-sized farms. GreenBot will be designed to help farmers remotely monitor and control greenhouse conditions when they are not physically present, offering an easier alternative to expensive and overly complicated existing systems.

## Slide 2

Upper System: Environmental Monitoring + Misting

Function - Critical parts
- Humidity sensor
- ESP 32 microcontroller
- Mister pump + nozzle
- Tank and Platform
- Cable/LED

Materials considered
- 3D-printed : PLA/PETG
- Nozzle/pump housing: plastic + metal internal pump parts
- Sensor housing: lightweight printed enclosure

Manufacturing
- 3D print tank platform and sensor mounts
- Purchase off-the-shelf sensor, ESP32, mister, and cables
- Assemble using fasteners and wire routing

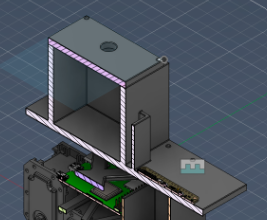
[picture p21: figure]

Water Tank

Nozzle for mist

ESP 32

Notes: The ESP 32 receives humidity data from the sensor and sends a control signal to a relay or MOSFET, which switches the misting on or off using external power.

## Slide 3

Temperature and Humidity
Sensor Module Data Sheet

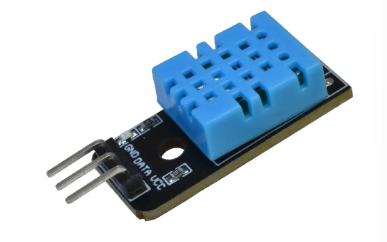
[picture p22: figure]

Data Sheets

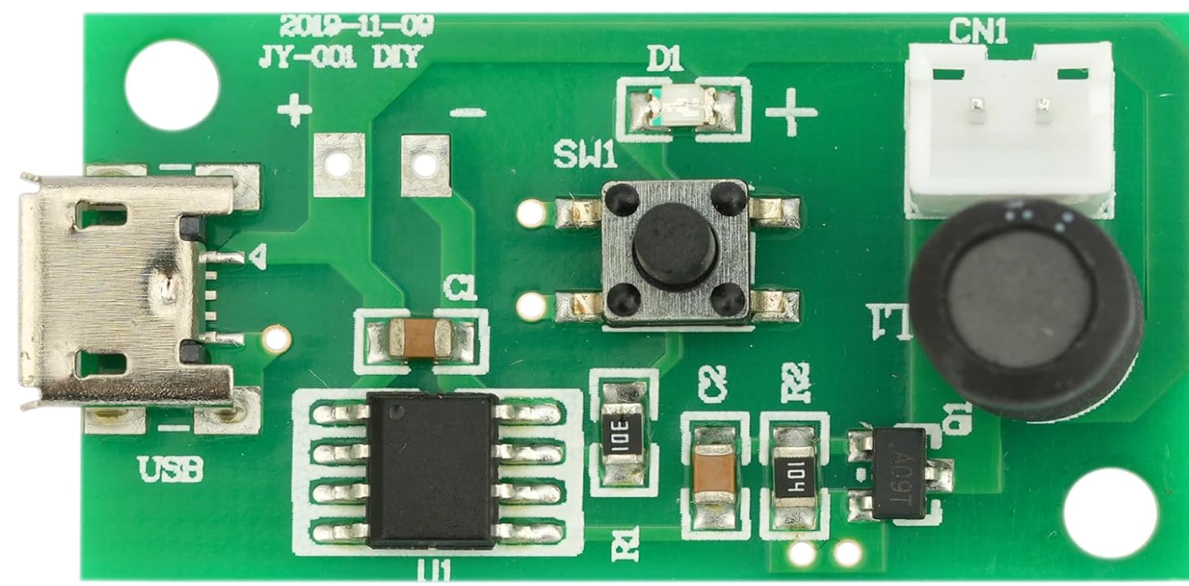
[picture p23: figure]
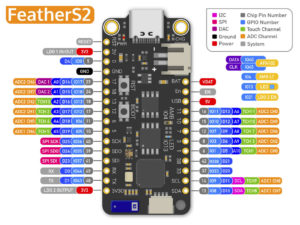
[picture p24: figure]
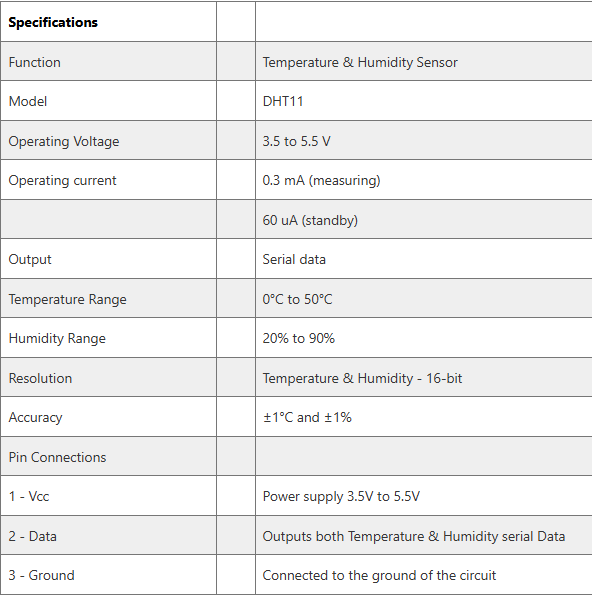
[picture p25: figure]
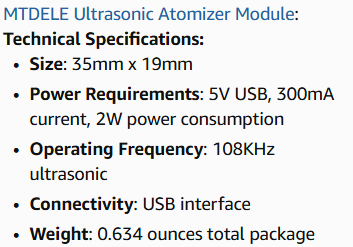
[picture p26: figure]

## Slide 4

Lower System: Walking/Support Mechanism


Function - Critical parts
- 4 legs
- Ball bearings(press fit)
- Dynamixel RX-24F actuators
- Chassis
- Distance holders/mounts


Materials considered
- Legs and chassis: 3D-printed PLA, PETG
- Bearings: metal
- Actuator housings: bought
- Fasteners/spacers: metal hardware

Raspberry Pi

2 legs each side

Manufacturing
- 3D print leg links, chassis, holders, and mounts
- Press-fit bearings into printed joints
- Assemble chassis with spacers and screws

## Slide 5


How Pi 4 and ESP 32 will communicate with each other


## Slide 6

3 Questions

- How can we make sure that chassis would support the water tank + electronics + battery?
- What improvements we need to incorporate in the design to provide enough torque for full loaded movement?
- Suggestions for printed material best for strength and lightweight.

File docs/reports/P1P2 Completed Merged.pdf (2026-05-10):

Project Assingment 1 & 2 (P1P2)
Team #22
Team members:
Bader AlKhawashki, Arunima Basu, Fritz Kuermayr, Aman Shah, Salvador Gonzalez

Deliverable 1: Team Project Agreement (for future reference)

1) Shop training:
Fritz Kuermayr will undergo the shop training. Aman Shah & Salvador Gonzalez will assist in the hardware, software, shop aspects, and other miscellaneous tasks
2) Sourcing parts:
Arunima Basu will be responsible for this aspect of the project, as well as communication with the teaching staff for the grant.
3) Deadlines:
Bader AlKhawashki will be responsible for project documentation (written tasks), submitting the work, and keeping track of project deadlines, which includes reminders to the team and team members.
4) Absence procedure that your team can use to address future concerns like these if they arise.
Emails and messages will be sent multiple times prior to escalating the issue to the teaching team.

Deliverable 2:
For farmers/gardeners who own greenhouses, it’s a robot that detects local humidity within a greenhouse and if it falls below a certain threshold, the robot extends a mechanism that sprays water mist and moves around the greenhouse to ensure proper humidification of the entire area. It also sprays nutrients on the soil every set number of hours using a retractable mechanism.
* Subject to Change.

(We opt in to be considered by the grant since this project improves the environment by taking care of plants in greenhouses.)

Deliverable 3:


Our Greenhouse robot scored the best, and we chose it as our primary concept prototype.

Deliverables 4 (Imported our slides below)


# GreenBot

## Greenhouse Robot : Mechatronics Prototype project

ME 102B
Team #22

Team Members:
Bader AlKhawashki, Arunima Basu, Fritz Kuermayr, Aman Shah, Salvador Gonzalez

# Del. 4A

Farmers work long hours, but they cannot always be inside their greenhouses to constantly check humidity and adding nutrients to soils every set number of hours.

Even small changes in these conditions can affect plant health and crop yield.

Many existing automation systems are either too expensive or too complicated for everyday use, especially for small and medium sized farms. Because of this, farmers need a simple and affordable way to monitor and control their greenhouse environment even when they are not physically present.

Our GreenBot is designed to solve this problem by helping farmers easily manage greenhouse conditions remotely and automatically, reducing stress, saving time, and improving crop growth.


# Del. 4B

GreenBot continuously monitors key
greenhouse | humidity | conditions.
When values drift outside target ranges, it automatically triggers the correct response (humidification).

Figure 1: Deliverable 4.B
Cartoon

* Degrees of Freedom:
robot moves in any
direction on the ground
using motors. Sprayer can
extend and retract (could
be switched to static
sprayer), humidity sensor
stays static

** Subject to change

# Del. 4C


Figure 2: Early prototype picture

Materials Exploration & Early Prototyping

We gathered basic materials to test key subsystems of our greenhouse robot, including a humidity sensor, small humidifier module, and a 4-legged robot. We also used a spray bottle with water to represent nutrient liquid delivery.

We play-acted the robot’s behavior by manually moving the mockup through a marked greenhouse area while taking humidity readings at different locations and heights. When humidity dropped below a set threshold, we activated the humidifier to observe how quickly and how far moisture spread.

Key Observations

- Humidity varies across the greenhouse; it is not evenly distributed
- A stationary humidifier does not provide full coverage
- Robot movement improves
humidity | and | liquid
distribution
- Sensor placement near plant
level | is | important

These tests confirmed that a mobile robot with automatic humidity control is a feasible and effective solution.

(* Design subject to change.)

# Del 4D


Figure 3: Deliverable 4.D Sketch *Subject to Change


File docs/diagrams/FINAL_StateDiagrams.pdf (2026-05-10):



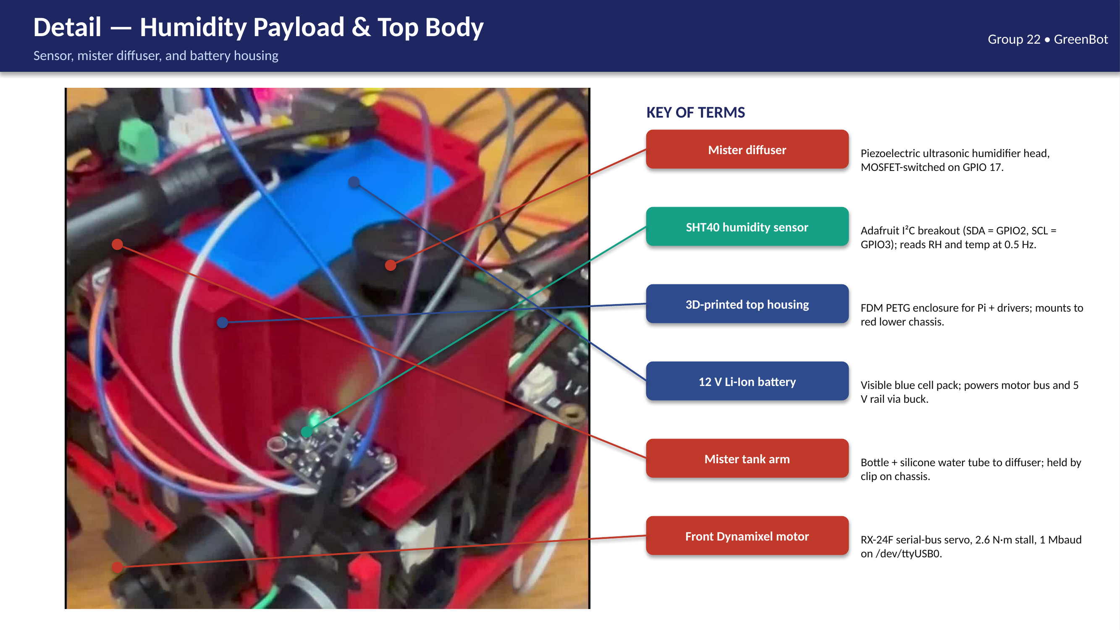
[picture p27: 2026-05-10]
docs/images/02_TopDetail.png

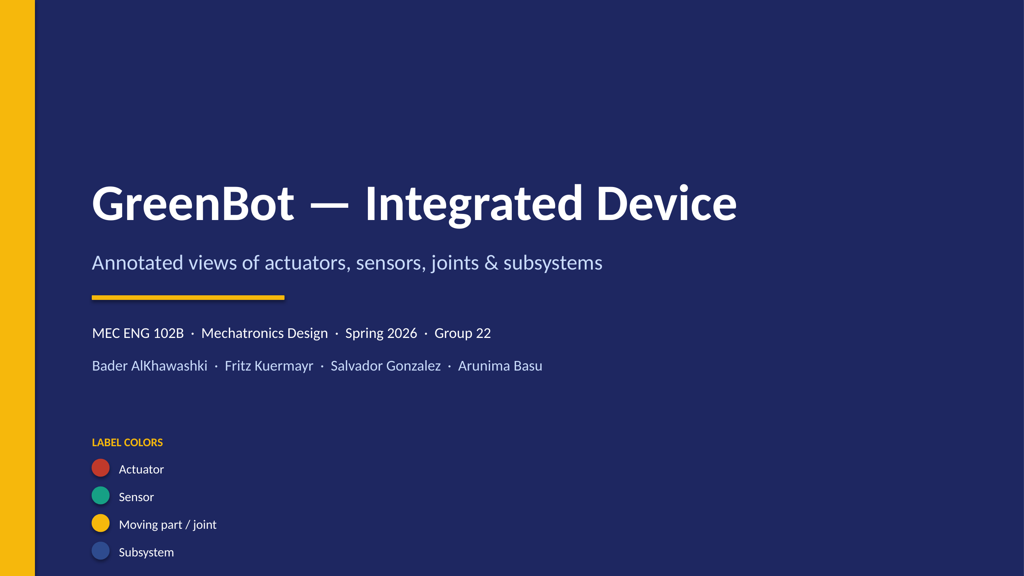
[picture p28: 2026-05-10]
docs/images/00_Title.png

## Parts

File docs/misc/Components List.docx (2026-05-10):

Components List:

Upper:

- Humidity sensor - https://projecthub.arduino.cc/rudraksh2008/temperature-and-humidity-sensor-with-arduino-1d52a6
- Microcontroller .- Adafruit V2 ESP 32 - https://github.com/adafruit/Adafruit_CAD_Parts/tree/main/5400%20ESP32%20Feather%20V2
- Mister (https://www.amazon.com/MTDELE-Humidifier-Atomization-Compatible-Incubation/dp/B0DC73SF6L?nsdOptOutParam=true) - Pump mechanism + nozzle - (Ordered)
- Cables
- Tank
- Digital Input - Power for Moisturizer - 3D Model missing

Control via Bluetooth or Cable

→ if via Bluetooth, we need a modem

Lower - Simple:

- 4 Motors (Provided by Tom) - 3D Model:

https://grabcad.com/library/motor-gb37y3530-1

- Microcontroler .

https://github.com/adafruit/Adafruit_CAD_Parts/tree/main/5400%20ESP32%20Feather%20V2

Cables

- Motor Drivers (Tom) - Cytron MD13S -https://drive.google.com/drive/folders/1MUIYsYif0C3330AlVv4YoFqafjgy4D-9
- Power Supply for Motors (Fritz) - https://www.amazon.com/SHAUOTR-Battery-5000mAh-Lithium-%EF%BC%8CCompatible/dp/B0DQM21PXX?th=1 - simply build a holder - i have the sketch
- Power Supply for Microcontroller (already given) - pls insert 3d Graph

Ask Tom

Lower - Bipedal:

6 Motors (Dynamixels)

Microcontroller

Board

Battery

Cables to connect

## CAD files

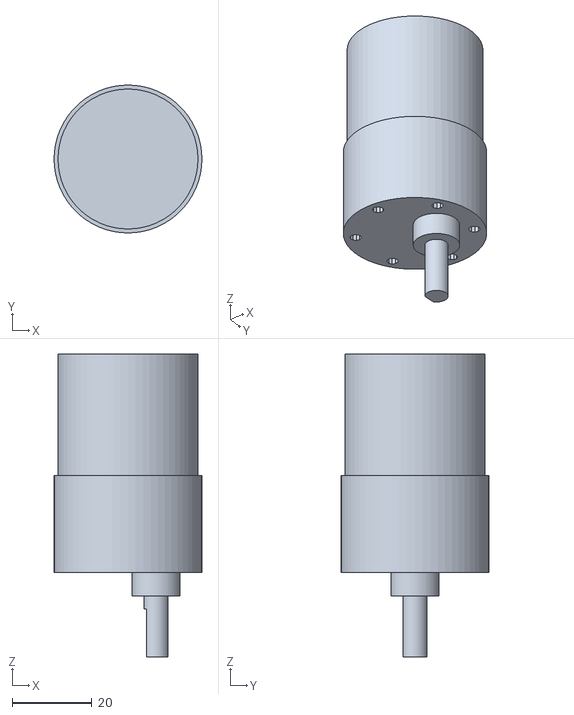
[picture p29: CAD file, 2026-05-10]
docs/cad/Motor_37D.stl
37.0 x 37.0 x 75.8

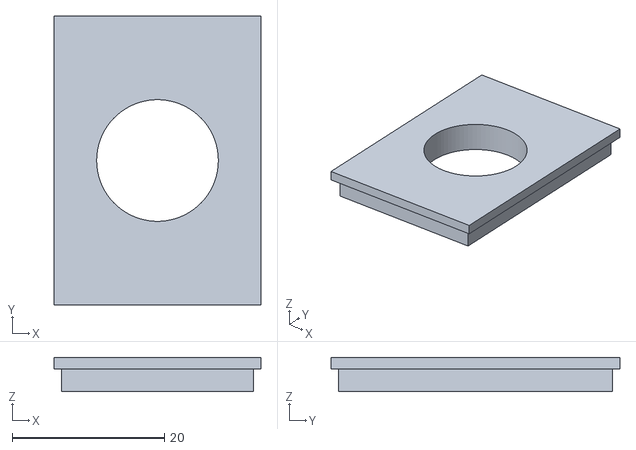
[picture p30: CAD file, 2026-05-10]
docs/cad/Lidv8.stl
27.2 x 38.0 x 4.50

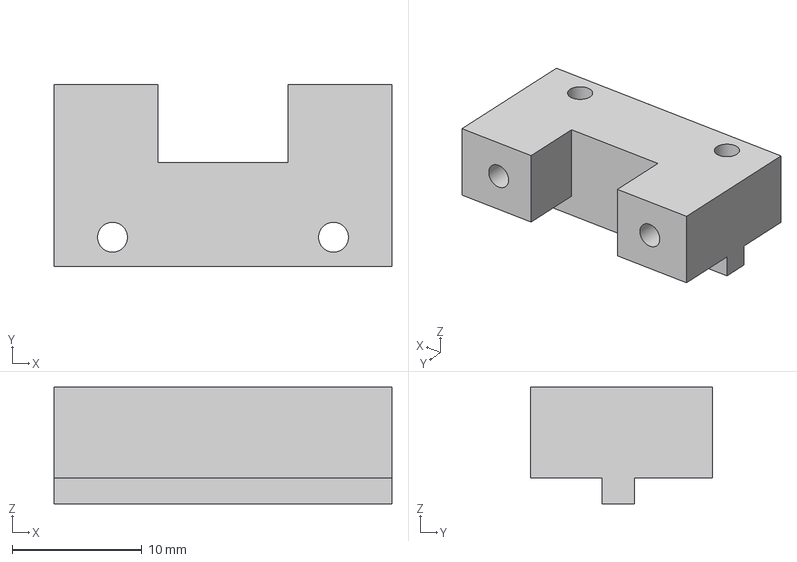
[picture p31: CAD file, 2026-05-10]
docs/cad/ESP platform.step
26.0 x 14.0 x 9.00 mm

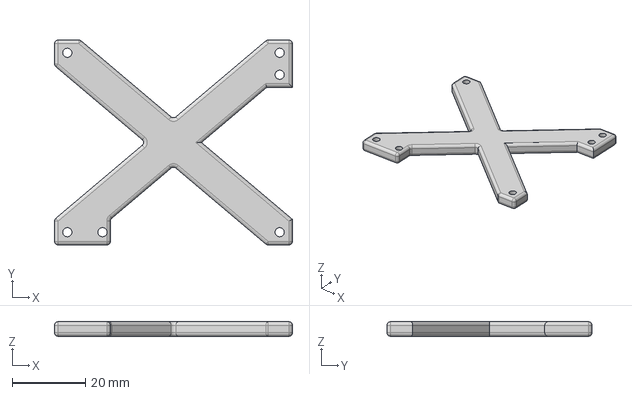
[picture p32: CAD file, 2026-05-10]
docs/cad/Controller_Holder.stp
65.0 x 56.0 x 4.00 mm

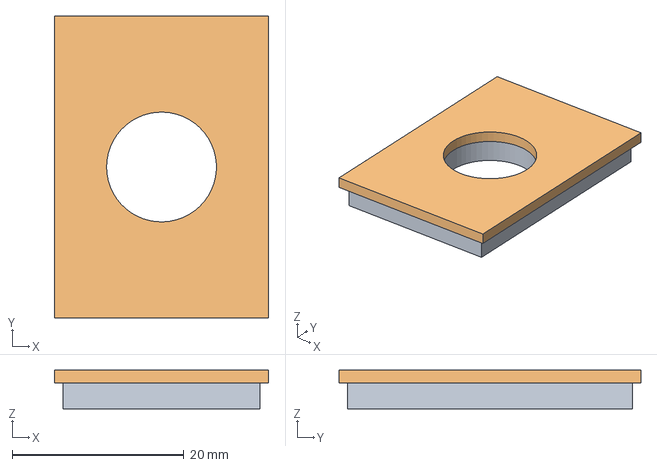
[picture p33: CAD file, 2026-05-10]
docs/cad/Lid.step
25.0 x 35.2 x 4.50 mm

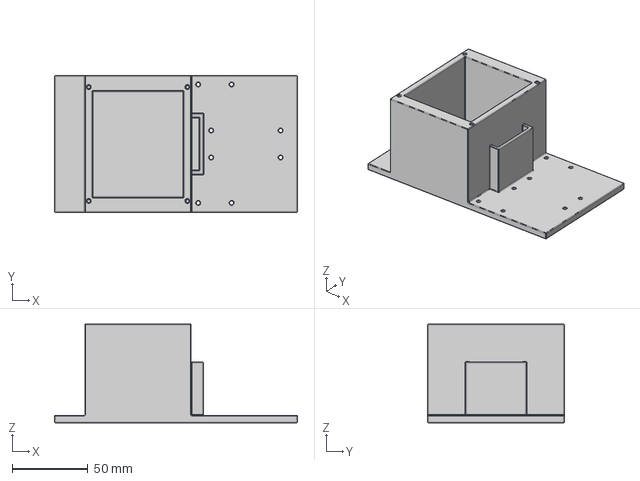
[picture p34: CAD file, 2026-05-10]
docs/cad/Upper_part.stp
160.0 x 90.0 x 65.0 mm

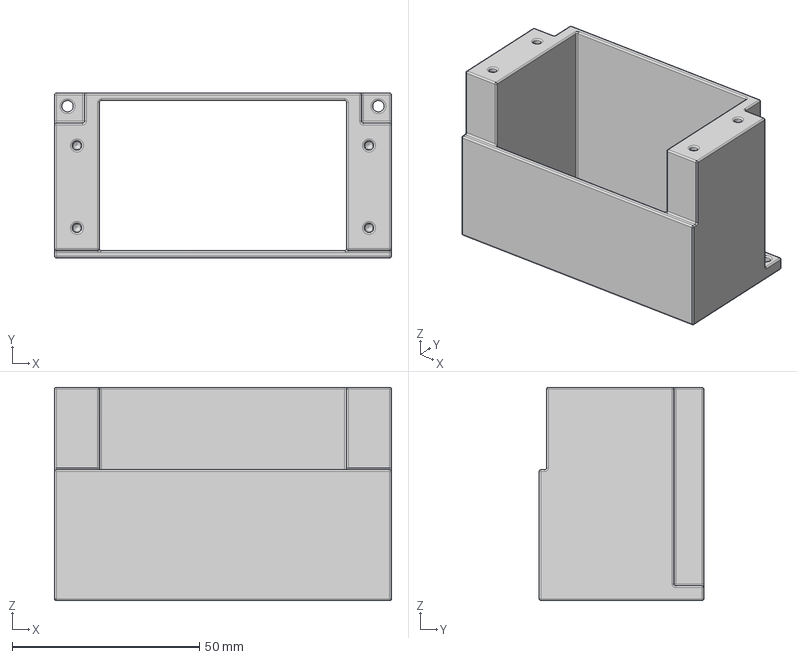
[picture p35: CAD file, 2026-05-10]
docs/cad/Battery-Holder.stp
90.0 x 44.0 x 57.0 mm

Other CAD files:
docs/cad/Controller_Holder.stl
docs/cad/ESP platform.stl
docs/cad/Lid.stl

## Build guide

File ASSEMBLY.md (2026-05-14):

# Robot Assembly

The robot is split into a **Lower Part** (chassis + locomotion + on-board
electronics) and an **Upper Part** (water tank + humidity-control
subsystem) that are bolted together with standoffs and tied into a
common electrical ground. Every load-bearing structural piece is
3D-printed; all fasteners and bearings are off-the-shelf.

## Bill of materials

### Lower Part

| Part | Qty |
|---|----:|
| Chassis (3D-printed) | 1 |
| Upper chassis (3-part print) | 1 |
| Upper legs (3D-printed) | 8 |
| Lower legs (3D-printed) | 8 |
| Ball bearings |  16 |
| Dynamixel RX-24F actuators | 8 |
| Roboteck K4P motor brackets | 9 |
| Motor controller holder (3D-printed) | 1 |
| Battery holder (3D-printed) | 1 |
| Distance holder M2.5 (20 mm) | 6 |
| Distance holder M2.5 (10 mm) | 6 |
| Screws & Nuts (M2.5 / M3) |  20 |
| Raspberry Pi 4 | 1 |
| U2D2 USB-to-Serial adapter | 1 |
| Diatone Mamba Micro 2 A BEC | 1 |
| 12 V 5000 mAh battery | 2 |
| USB-C to USB-B cable | 1 |
| Arduino USB dongle | 1 |

### Upper Part

| Part | Qty |
|---|----:|
| 3D-printed tank + platform | 1 |
| 3D-printed LED housing | 1 |
| ESP32 Feather V2 microcontroller | 1 |
| SHT40 humidity / temperature sensor | 1 |
| DFRobot Gravity MOSFET module | 1 |
| Mister (pump + nozzle) | 1 |
| Washers |  10 |
| Fasteners |  10 |
| Gaskets |  10 |
| Cables (assorted lengths, dupont/silicone)  |  30 |

## Lower Part assembly

### Mechanical chassis and legs

The base chassis is the single largest 3D-printed piece and forms the
flat platform that everything else mounts onto. Each of the four legs
is built from one **upper leg** and one **lower leg**, both 3D-printed,
connected at the knee by a single **ball bearing** pair that allows the
lower leg to swing freely on the knee shaft (two bearings per knee × 4
knees = 8 bearings). The remaining 8 ball bearings sit at the hip
joints, supporting the upper-leg shaft against the chassis so the
Dynamixel does not carry the radial load itself. With both bearing
pairs installed the legs spin smoothly under their own weight, which is
the first sanity-check before any motor is wired.

### Servomotors and brackets

Eight **Dynamixel RX-24F** actuators are screwed into **Roboteck K4P
motor brackets** — one bracket carries each motor; the ninth bracket
sits centrally on the chassis as a cable-routing anchor. Each leg gets
two motors: one driving the hip joint (rotates the upper leg about its
mounting point on the chassis) and one driving the knee (rotates the
lower leg relative to the upper leg). The K4P brackets keep the motor
output shaft concentric with the bearing axis so no side load reaches
the gear train.

### On-board electronics shelf

A separate 3D-printed **motor controller holder** mounts on top of the
chassis and carries the **Raspberry Pi 4**, the **U2D2 adapter**, and
the **Diatone Mamba Micro 2 A BEC**. The four M2.5 standoffs that come
with the Pi (and the 10 mm distance holders) raise the Pi above the
holder so the GPIO header and USB ports stay accessible. The two
**12 V 5000 mAh batteries** sit on the dedicated **battery holder**,
low and central, for a low centre of gravity; they are wired in
parallel through a small power-distribution junction so total capacity
roughly doubles while voltage stays at 12 V.

### Lower-Part wiring

The motor bus is a daisy chain of all eight Dynamixels with the
standard four-pin Dynamixel cables; the chain terminates at the
**U2D2** which plugs into the Pi via the **USB-B → USB-C cable**. The
12 V battery rail feeds the Dynamixels directly (via a small power hub
that is part of the daisy chain) and also feeds the **BEC**, which
steps the rail down to 5 V for the Pi. The Pi can therefore be powered
from the battery alone — no separate Pi supply is needed in the field.

```text
12 V battery (×2 parallel) ──┬───►  U2D2 / Dynamixel bus  ───►  8 × RX-24F
                              │
                              └───►  BEC  ────►  5 V  ────►  Raspberry Pi 4

Raspberry Pi 4  ──── USB-C to USB-B ────►  U2D2  ──── 4-pin RS-485 ────►  motor chain
```

The **Arduino USB dongle** is used as the USB-C programming/charging
cable for the ESP32 Feather V2 in the Upper Part; during normal
operation it can be unplugged because the Feather runs from its own
LiPo or from the BEC rail if a tap is fitted.

## Upper Part assembly

### Tank and platform

The **3D-printed tank + platform** is a single combined piece: the
lower half holds the water for the mister, the upper half is a flat
mounting surface for the electronics. The tank seam and the lid
opening are sealed with the **gaskets**; **washers** distribute the
clamping load from the **fasteners** so the print does not crack.
The **mister (pump + nozzle)** sits inside the tank with its nozzle
poking through a sealed opening on the top so the spray plume is
released upward.

### Humidity electronics

The **ESP32 Feather V2** is mounted on the platform with two M2.5 ×
10 mm standoffs, and the **SHT40 sensor** is placed next to it (or
plugged into the Feather's STEMMA QT connector). The **DFRobot Gravity
MOSFET module** sits between the platform and the mister: its
screw-terminal input is fed by an external 5 V supply, its output
switches the mister's positive lead. The **3D-printed LED housing**
holds an indicator LED that lights when the mister is active — wired
in parallel with the MOSFET signal LED or directly across the mister
output (a current-limiting resistor in series is required).

### Upper-Part wiring

```text
ESP32 Feather V2 GPIO27    ───►  MOSFET SIG (purple)
ESP32 Feather V2 3V        ───►  MOSFET VCC (blue)  +  SHT40 VCC (red)
ESP32 Feather V2 GND (L)   ───►  MOSFET GND (gray)
ESP32 Feather V2 GND (R)   ───►  SHT40 GND  (blue)
ESP32 Feather V2 SDA / SCL ───►  SHT40 SDA / SCL  (white / orange)

5 V external supply  ───►  MOSFET VIN  ───►  MOSFET VOUT  ───►  Mister +
5 V external supply GND  ─────────────────────────────────────►  Mister −
```

The full pin map for the Feather, including the optional override
switch on `GPIO33`, lives in
[`software/wiring_map_esp32.md`](software/wiring_map_esp32.md).

## Joining Upper and Lower parts

The Upper Part sits on top of the **upper chassis** (the 3-part print
that closes off the locomotion deck) and is held by the **six M2.5 ×
20 mm distance holders**, which raise the tank a few centimetres above
the chassis so the mister plume can escape sideways without hitting
the Pi. The six 10 mm holders stay below in the Lower Part for the Pi
and motor-controller mounts. **Screws and nuts** clamp the standoffs
through both the upper chassis and the Upper-Part platform.

A single short cable runs from the Upper-Part `GND` rail down to a
chassis-side `GND` point so the **two power supplies** (the 12 V motor
battery and the 5 V mister supply) share a reference with the Feather.
Without this single ground bond the MOSFET gate driver loses its
reference and the mister will not switch reliably.

## Bring-up order

The three subsystems are verified individually before any combined
test:

1. **Dynamixel chain.** Power the motor rail, plug in the U2D2, and
   run `python3 tools/dynamixel_scan.py` on the Pi. Confirm all eight
   motors appear with the expected IDs.
2. **MOSFET + mister.** With the ESP32 powered by USB only, run
   `esp32_mosfet_test.ino` and toggle the MOSFET manually via Serial.
   Verify the indicator LED switches and that the mister runs when
   the external 5 V supply is connected.
3. **Humidity sensor.** Flash `esp32_sht40_test.ino` and confirm
   sensible temperature and RH readings (breath test: humidity should
   spike and recover within seconds).

Once each of the three checks is green, flash
`esp32_humidity_control.ino` (or `..._switch.ino` if the toggle switch
is fitted), mount the Upper Part onto the Lower Part, connect the
common ground wire, and power up the batteries. The Pi handles
locomotion; the Feather runs closed-loop humidity regulation
independently in parallel.

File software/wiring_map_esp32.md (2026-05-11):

# ESP32 Feather V2 — Master Wiring Map

Single reference covering every component connected to the Feather V2 in
this project. Per-sketch details are kept in:

- [`wiring_humidity_control.md`](wiring_humidity_control.md) — sensor-only variant
- [`wiring_humidity_control_switch.md`](wiring_humidity_control_switch.md) — with manual switch

## Pin overview

```text
                        ┌──── USB-C ────┐
                        │    [Reset]    │
                RST  ───┤               ├───  VBUS  (5 V from USB)
       ★ 3V       ●─────┤               ├───  EN
                NC  ───┤   Adafruit     ├───  VBAT  (LiPo via JST-PH)
       ★ GND      ●─────┤   ESP32       ├───  GND   ★ (right)
                A0   ───┤   Feather V2  ├───  13    (red on-board LED)
                A1   ───┤               ├───  12
                A2   ───┤               ├───  27    ★  MOSFET SIG
                A3   ───┤               ├───  33    ★  Switch input
                A4   ───┤               ├───  15
                A5   ───┤               ├───  32
                SCK  ───┤               ├───  14
               MOSI  ───┤               ├───  SDA   ★  (= GPIO22) I2C data
               MISO  ───┤               ├───  SCL   ★  (= GPIO20) I2C clock
                RX   ───┤               ├───  38
                TX   ───┤  [STEMMA QT]  ├───  37
                        └───────────────┘

★ = pins used by this project.
```

## Component-by-component

### MOSFET module (DFRobot Gravity, active-low)

| Wire | Color | Goes to Feather pin |
|---|---|---|
| SIG | purple  | `27` |
| VCC | blue | `3V` (shared) |
| GND | gray | `GND` (left) |

Notes:
- The module is **active-low**: `27` = LOW means MOSFET ON / status LED on.
- The Feather pin idles HIGH so the mister cannot accidentally turn on
  while the chip is booting.

### SHT40 humidity / temperature sensor (I2C)

| Wire | Color | Goes to Feather pin |
|---|---|---|
| VCC | red | `3V` (shared) |
| GND | blue | `GND` (right) |
| SDA | white | `SDA`  (= GPIO22) |
| SCL | orange  | `SCL`  (= GPIO20) |

Alternative: plug an Adafruit STEMMA QT cable straight into the QT
connector at the bottom of the Feather V2 — same wiring, no header
soldering.

### Manual switch (only used by `esp32_humidity_control_switch`)

| Wire | Goes to Feather pin |
|---|---|
| Switch pin 1| `33` |
| Switch pin 2| `GND` (shared, see note below) |

Notes:
- The Feather V2 has only two GND pins on its headers and both are
  already used. Twist the switch GND with the MOSFET GND (gray) and put
  both leads into the same `GND` (left) pin.
- Polarity of the switch is irrelevant; the ESP32 holds `33` HIGH
  internally (`INPUT_PULLUP`), the switch pulls it to GND when closed.

## Shared rails

| Rail | Devices sharing it |
|---|---|
| `3V` | MOSFET VCC (blue) + SHT40 VCC (red) |
| `GND` (L) | MOSFET GND (gray) + optional switch GND |
| `GND` (R) | SHT40 GND (blue) |

To share `3V`: twist the two wires together and plug them into the same
header hole, or break it out on a small breadboard.

## External supply for the mister

The Feather **does not** power the mister. A separate supply (typically
5 V) feeds the mister through the MOSFET module.

```text
ext. supply +V   ────►  MOSFET VIN   (screw terminal)
ext. supply GND  ────►  MOSFET GND   (screw terminal)
ext. supply GND  ────►  Feather GND   ←  REQUIRED: common ground
MOSFET VOUT      ────►  Mister +
ext. supply GND  ────►  Mister −
```

Without the common ground between supply and Feather the MOSFET gate
driver has no stable reference and the FET will not switch reliably.

## Pin-to-purpose table (quick lookup)

| Feather V2 pin | Used by | What |
|---|---|---|
| `3V` | MOSFET, SHT40 | 3.3 V logic supply |
| `GND` (left) | MOSFET (+ switch, if used) | ground |
| `GND` (right) | SHT40 | ground |
| `27` | MOSFET | SIG (active-low) |
| `33` | Switch (switch sketch only) | input, pull-up |
| `SDA` (= GPIO22) | SHT40 | I2C data |
| `SCL` (= GPIO20) | SHT40 | I2C clock |

## Per-sketch usage

| Sketch | Uses 27 | Uses 33 | Uses I2C |
|---|:---:|:---:|:---:|
| `esp32_mosfet_test` | ✓ | | |
| `esp32_sht40_test` | | | ✓ |
| `esp32_humidity_control` | ✓ | | ✓ |
| `esp32_humidity_control_switch` | ✓ | ✓ | ✓ |

You can swap between any two sketches without re-wiring anything — the
switch sketch just adds the button on `33`, no other pins change.

## Powering the Feather itself

| Source | Connector | Notes |
|---|---|---|
| USB-C from PC | USB-C port | Programming and 5 V supply |
| USB-C charger | USB-C port | Standalone, 5 V from any USB charger |
| LiPo battery | JST-PH on the underside | Single-cell 3.7 V; on-board charger via USB-C |

The mister is always powered by its own external supply, regardless of
how the Feather is powered.

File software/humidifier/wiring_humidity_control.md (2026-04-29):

# Wiring — `esp32_humidity_control`

Variant **without switch**, fully automatic based on the sensor reading.

## Pin assignment

| Function | Feather V2 pin | Wire color |
|---|---|---|
| MOSFET SIG | `27` | purple |
| MOSFET VCC | `3V` | blue (MOSFET) |
| MOSFET GND | `GND` (left) | gray |
| SHT40 VCC | `3V` | red |
| SHT40 GND | `GND` (right) | blue (SHT40) |
| SHT40 SDA | `SDA`  (= GPIO22)  | white |
| SHT40 SCL | `SCL`  (= GPIO20)  | orange |

`3V` is shared between MOSFET VCC and SHT40 VCC — twist the two leads
together and stick them into the same `3V` pin (or use a small breadboard).

## ASCII diagram

```text
                       ┌──── USB-C ────┐
                       │    [Reset]    │
               RST  ───┤               ├───  VBUS
   ┌──── 3V        ●───┤   Adafruit    ├───  EN
   │           NC  ───┤   ESP32        ├───  VBAT
   │   ┌── GND  ●───┤   Feather V2   ├───  GND  ●──┐
   │   │       A0   ───┤                ├───  13 (LED)
   │   │       A1   ───┤                ├───  12
   │   │       A2   ───┤                ├───  27   ●──┐
   │   │       A3   ───┤                ├───  33      │
   │   │       A4   ───┤                ├───  15      │
   │   │       A5   ───┤                ├───  32      │
   │   │       SCK  ───┤                ├───  14      │
   │   │      MOSI  ───┤                ├───  SDA  ●──│──┐
   │   │      MISO  ───┤                ├───  SCL  ●──│─┐│
   │   │       RX   ───┤                ├───  38      │ ││
   │   │       TX   ───┤  [STEMMA QT]   ├───  37      │ ││
   │   │            └────────────────┘             │ ││
   │   │                                            │ ││
   │   │   MOSFET module (DFRobot Gravity)          │ ││
   │   │   ────────────────────────────             │ ││
   │   │   gray   (GND)  ─┐                          │ ││
   │   │                  └─────────► GND (left)     │ ││
   ├───│── blue   (VCC)  ─────────► 3V               │ ││
   │   │   purple (SIG)  ─────────────────────────── │─┘│
   │   │                                             │  │
   │   │   SHT40                                     │  │
   │   │   ─────                                     │  │
   ├───│── red    (VCC)  ─────────► 3V               │  │
   │   │   blue   (GND)  ─────────► GND (right) ─────┘  │
   │   │   white  (SDA)  ─────────► SDA                 │
   │   │   orange (SCL)  ────────────────────────────── ┘
```

## Power

- **Feather:** USB-C, or a single-cell 3.7 V LiPo on the JST-PH connector.
- **Mister:** external supply on the MOSFET screw terminals `VIN` / `GND`.
- **Required:** external-supply `GND`  ↔  Feather `GND`  (common ground).

```text
ext. supply +V   ────►  MOSFET VIN   (screw terminal)
ext. supply GND  ────►  MOSFET GND   (screw terminal)
ext. supply GND  ────►  Feather GND  (common ground - mandatory)
MOSFET VOUT      ────►  Mister +
ext. supply GND  ────►  Mister −
```

## Logic summary

| RH | MOSFET |
|---|---|
| < 78.0 % | **ON** (mister runs) |
| ≥ 80.0 % | OFF (sensor blocks) |
| 78 – 80 % | hold current state |
| sensor unreachable | OFF (fail-safe) |

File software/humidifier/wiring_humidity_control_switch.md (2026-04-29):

# Wiring — `esp32_humidity_control_switch`

Variant **with toggle / slide switch** for a manual on/off request; the
sensor still blocks the MOSFET above the upper threshold.

The switch position directly maps to `userWantsOn`:

- switch **closed** (pin → GND, LOW) → `userWantsOn = YES`
- switch **open**   (pin = HIGH)     → `userWantsOn = no`

For a momentary push-button the mister would only run while the button is
held — in that case use the Serial `t` command instead.

## Pin assignment

| Function | Feather V2 pin | Wire color |
|---|---|---|
| MOSFET SIG | `27` | purple |
| MOSFET VCC | `3V` | blue (MOSFET) |
| MOSFET GND | `GND` (left) | gray |
| SHT40 VCC | `3V` | red |
| SHT40 GND | `GND` (right) | blue (SHT40) |
| SHT40 SDA | `SDA`  (= GPIO22)  | white |
| SHT40 SCL | `SCL`  (= GPIO20)  | orange |
| **Switch pin 1**  | **`33`** | any |
| **Switch pin 2**  | **`GND` (shared)** | any |

`3V` is shared between MOSFET VCC and SHT40 VCC. The **switch GND** has to
share one of the two GND pins with either MOSFET GND or SHT40 GND because
the Feather V2 only has two GND pins on its headers. Easiest: twist the
switch GND with the MOSFET GND (gray) and stick both into `GND` (left).

Switch polarity does not matter — when the switch is closed, `33` is
pulled to `GND` through the switch; when open, the ESP32 internally pulls
the pin HIGH (`INPUT_PULLUP`).

## ASCII diagram

```text
                       ┌──── USB-C ────┐
                       │    [Reset]    │
               RST  ───┤               ├───  VBUS
   ┌──── 3V        ●───┤   Adafruit    ├───  EN
   │           NC  ───┤   ESP32        ├───  VBAT
   │   ┌── GND  ●───┤   Feather V2   ├───  GND  ●──┐
   │   │       A0   ───┤                ├───  13 (LED)
   │   │       A1   ───┤                ├───  12
   │   │       A2   ───┤                ├───  27   ●──┐
   │   │       A3   ───┤                ├───  33   ●─┐│
   │   │       A4   ───┤                ├───  15     ││
   │   │       A5   ───┤                ├───  32     ││
   │   │       SCK  ───┤                ├───  14     ││
   │   │      MOSI  ───┤                ├───  SDA  ●─││──┐
   │   │      MISO  ───┤                ├───  SCL  ●─││─┐│
   │   │       RX   ───┤                ├───  38     ││ ││
   │   │       TX   ───┤  [STEMMA QT]   ├───  37     ││ ││
   │   │            └────────────────┘            ││ ││
   │   │                                           ││ ││
   │   │   MOSFET module (DFRobot Gravity)         ││ ││
   │   │   ────────────────────────────            ││ ││
   │   │   gray   (GND)  ──┐                       ││ ││
   │   │                   ├──► GND (left)         ││ ││
   │   │   Switch pin 2 ───┘    (shared)           ││ ││
   │   │                                           ││ ││
   ├───│── blue   (VCC)  ──────► 3V                ││ ││
   │   │   purple (SIG)  ─────────────────────────  │ ││
   │   │   Switch pin 1  ─────────────────────────── ┘ ││
   │   │                                                 ││
   │   │   SHT40                                         ││
   │   │   ─────                                         ││
   ├───│── red    (VCC)  ──────► 3V                      ││
   │   │   blue   (GND)  ──────► GND (right) ────────────┘│
   │   │   white  (SDA)  ──────► SDA                      │
   │   │   orange (SCL)  ───────────────────────────────── ┘
```

## Power

- **Feather:** USB-C, or a single-cell 3.7 V LiPo on the JST-PH connector.
- **Mister:** external supply on the MOSFET screw terminals `VIN` / `GND`.
- **Required:** external-supply `GND`  ↔  Feather `GND`  (common ground).

```text
ext. supply +V   ────►  MOSFET VIN   (screw terminal)
ext. supply GND  ────►  MOSFET GND   (screw terminal)
ext. supply GND  ────►  Feather GND  (common ground - mandatory)
MOSFET VOUT      ────►  Mister +
ext. supply GND  ────►  Mister −
```

## Logic summary

| Switch position | RH | MOSFET |
|---|---|---|
| open (`userWantsOn=no`) | any | OFF |
| closed (`userWantsOn=YES`)  | < 78.0 % | **ON** |
| closed | ≥ 80.0 % | OFF (sensor blocks) |
| closed | 78 – 80 % | hold current state |
| any | sensor error | OFF (fail-safe) |

`userWantsOn` always follows the current switch position. If the switch
stays closed while RH rises above 80 %, the mister is forced off — once
RH drops below 78 % again, it resumes automatically.

## Testing without a hardware switch

In the Serial Monitor (115200 baud, line ending "Newline") send the
character `t` — same effect as flipping the switch. Use `s` for the
current status and `h` for help.

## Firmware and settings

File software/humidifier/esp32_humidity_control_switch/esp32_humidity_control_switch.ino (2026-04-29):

// Humidity controller WITH switch, for Adafruit ESP32 Feather V2.
// SHT40 + DFRobot Gravity MOSFET (active-low) + toggle/slide switch.
//
// Behaviour:
//   The switch position directly maps to "user request":
//     switch closed (pin LOW)  -> userWantsOn = YES
//     switch open   (pin HIGH) -> userWantsOn = no
//   MOSFET is ON exactly when:
//     userWantsOn = true  AND  humidityBlocks = false  (hysteresis allows it)
//
//   This works for both a toggle (latching) and a slide switch: every
//   physical position change immediately changes the state. (For a
//   momentary push-button the mister would only run while the button is
//   held - use the Serial 't' command instead in that case.)
//
//   Hysteresis:
//     RH >= 80.0 %  -> block
//     RH <  78.0 %  -> release
//     between -> hold current block state
//
//   Sensor error / sensor missing -> MOSFET forced OFF (fail-safe).
//
// Pins (Feather V2):
//   MOSFET SIG (purple) -> 27
//   MOSFET VCC (blue)   -> 3V
//   MOSFET GND (gray)   -> GND  (left side)
//   SHT40  VCC (red)    -> 3V
//   SHT40  GND (blue)   -> GND  (right side)
//   SHT40  SDA (white)  -> SDA  (GPIO22)
//   SHT40  SCL (orange) -> SCL  (GPIO20)
//   Switch              -> GPIO33  and  GND  (INPUT_PULLUP, closed = LOW)
//
// Note about the switch GND:
//   The Feather V2 only has 2 GND pins on its headers, both already in
//   use. Twist the switch GND together with the MOSFET GND or the SHT40
//   GND and plug both leads into the same GND pin - electrically
//   identical.
//
// Library: Adafruit SHT4x (Library Manager).
//
// Serial: 115200 baud, line ending "Newline".
//   t -> toggle userWantsOn (works without a hardware switch)
//   s -> show status
//   h -> help

#include <Wire.h>
#include "Adafruit_SHT4x.h"

// ---------- Configuration ----------
const uint8_t MOSFET_PIN = 27;
const uint8_t BUTTON_PIN = 33;
const bool    MOSFET_ACTIVE_LOW = true;

const float HUMIDITY_LIMIT_HIGH = 80.0;  // >= -> block
const float HUMIDITY_LIMIT_LOW  = 78.0;  // <   -> release

const uint32_t SAMPLE_INTERVAL_MS = 2000;
const uint32_t DEBOUNCE_MS = 40;

// ---------- Runtime state ----------
Adafruit_SHT4x sht4;
bool sensorOk = false;

bool userWantsOn = false;
bool humidityBlocks = true;     // boot default: blocked until first valid reading
bool currentMosfetOn = false;

uint32_t lastSampleMs = 0;
float lastRh = NAN;
float lastTemp = NAN;

int lastButtonReading = HIGH;
int stableButtonState = HIGH;
uint32_t lastButtonChangeMs = 0;

// ---------- Helpers ----------
void writeMosfet(bool on) {
  uint8_t level;
  if (MOSFET_ACTIVE_LOW) {
    level = on ? LOW : HIGH;
  } else {
    level = on ? HIGH : LOW;
  }
  digitalWrite(MOSFET_PIN, level);
}

void applyMosfetIfChanged(bool desiredOn) {
  if (desiredOn == currentMosfetOn) return;
  currentMosfetOn = desiredOn;
  writeMosfet(currentMosfetOn);
  Serial.print(">> MOSFET ");
  Serial.println(currentMosfetOn ? "ON" : "OFF");
}

void printStatus() {
  Serial.print("[status] RH=");
  if (isnan(lastRh)) {
    Serial.print("--.--");
  } else {
    Serial.print(lastRh, 2);
  }
  Serial.print(" %  T=");
  if (isnan(lastTemp)) {
    Serial.print("--.--");
  } else {
    Serial.print(lastTemp, 2);
  }
  Serial.print(" C  userWantsOn=");
  Serial.print(userWantsOn ? "YES" : "no ");
  Serial.print("  block=");
  Serial.print(humidityBlocks ? "YES" : "no ");
  Serial.print("  MOSFET=");
  Serial.println(currentMosfetOn ? "ON" : "OFF");
}

void printHelp() {
  Serial.println();
  Serial.println("Commands:");
  Serial.println("  t -> toggle userWantsOn");
  Serial.println("  s -> status");
  Serial.println("  h -> help");
}

// ---------- Setup ----------
void setup() {
  // Force MOSFET OFF before pinMode takes effect (active-low: HIGH = off).
  uint8_t idleLevel = MOSFET_ACTIVE_LOW ? HIGH : LOW;
  digitalWrite(MOSFET_PIN, idleLevel);
  pinMode(MOSFET_PIN, OUTPUT);
  digitalWrite(MOSFET_PIN, idleLevel);

  pinMode(BUTTON_PIN, INPUT_PULLUP);

  Serial.begin(115200);
  delay(200);
  Serial.println();
  Serial.println("Humidity controller (with switch) starting...");

#if defined(I2C_POWER)
  // Feather V2: enable the I2C / STEMMA QT power rail.
  pinMode(I2C_POWER, OUTPUT);
  digitalWrite(I2C_POWER, HIGH);
  delay(10);
#endif

  Wire.begin();

  if (sht4.begin()) {
    sensorOk = true;
    sht4.setPrecision(SHT4X_HIGH_PRECISION);
    sht4.setHeater(SHT4X_NO_HEATER);
    Serial.print("SHT4x found, serial 0x");
    Serial.println(sht4.readSerial(), HEX);
  } else {
    sensorOk = false;
    Serial.println("SHT40 NOT found - MOSFET stays OFF (fail-safe).");
  }

  Serial.print("Thresholds: block at RH >= ");
  Serial.print(HUMIDITY_LIMIT_HIGH, 1);
  Serial.print(" %, release at RH < ");
  Serial.print(HUMIDITY_LIMIT_LOW, 1);
  Serial.println(" %");

  printHelp();
  printStatus();
}

// ---------- Sensor / hysteresis ----------
void readSensorIfDue() {
  uint32_t now = millis();
  if (now - lastSampleMs < SAMPLE_INTERVAL_MS) return;
  lastSampleMs = now;

  if (!sensorOk) {
    humidityBlocks = true;
    return;
  }

  sensors_event_t humidity, temp;
  if (!sht4.getEvent(&humidity, &temp)) {
    Serial.println("Sensor read failed - blocking MOSFET.");
    humidityBlocks = true;
    return;
  }

  lastTemp = temp.temperature;
  lastRh = humidity.relative_humidity;

  Serial.print("T = ");
  Serial.print(lastTemp, 2);
  Serial.print(" C   RH = ");
  Serial.print(lastRh, 2);
  Serial.println(" %");

  if (lastRh >= HUMIDITY_LIMIT_HIGH) {
    if (!humidityBlocks) {
      Serial.println(">> Humidity limit reached - blocking MOSFET.");
    }
    humidityBlocks = true;
  } else if (lastRh < HUMIDITY_LIMIT_LOW) {
    if (humidityBlocks) {
      Serial.println(">> Humidity dropped below release threshold - allowed again.");
    }
    humidityBlocks = false;
  }
}

// ---------- Switch ----------
// After debounce the switch position is mapped directly onto userWantsOn.
// This makes both toggle/latching and slide switches usable: each
// position change leads to exactly one state change.
void readButton() {
  int reading = digitalRead(BUTTON_PIN);
  uint32_t now = millis();

  if (reading != lastButtonReading) {
    lastButtonReading = reading;
    lastButtonChangeMs = now;
    return;
  }

  if ((now - lastButtonChangeMs) < DEBOUNCE_MS) return;

  if (reading != stableButtonState) {
    stableButtonState = reading;
    bool desired = (stableButtonState == LOW);  // LOW = closed = ON
    if (desired != userWantsOn) {
      userWantsOn = desired;
      Serial.print("Switch -> userWantsOn=");
      Serial.println(userWantsOn ? "YES" : "no");
    }
  }
}

// ---------- Serial commands ----------
void readSerial() {
  while (Serial.available()) {
    int c = Serial.read();
    switch (c) {
      case 't':
      case 'T':
        userWantsOn = !userWantsOn;
        Serial.print("Serial toggle -> userWantsOn=");
        Serial.println(userWantsOn ? "YES" : "no");
        break;
      case 's':
      case 'S':
        printStatus();
        break;
      case 'h':
      case 'H':
        printHelp();
        break;
      case '\r':
      case '\n':
      case ' ':
        break;
      default:
        Serial.print("Unknown command: ");
        Serial.println((char)c);
        break;
    }
  }
}

// ---------- Loop ----------
void loop() {
  readSensorIfDue();
  readButton();
  readSerial();

  bool desired = userWantsOn && !humidityBlocks;
  applyMosfetIfChanged(desired);
}

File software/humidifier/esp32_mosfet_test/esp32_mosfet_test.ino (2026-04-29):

// MOSFET test for Adafruit ESP32 Feather V2
// Manual control of GPIO27 (-> Gravity MOSFET SIG, purple wire) via Serial.
// Purpose: verify that the MOSFET cleanly switches the external supply.
//
// MOSFET module -> Feather:
//   purple (SIG) -> 27
//   blue   (VCC) -> 3V
//   gray   (GND) -> GND
//
// NOTE: This module is active-low.
//   SIG LOW  -> MOSFET ON  (status LED on)
//   SIG HIGH -> MOSFET OFF (status LED off)
// The code below inverts the polarity so "1" still means MOSFET ON.
//
// Serial commands (115200 baud, line ending "Newline"):
//   1  -> MOSFET ON  (GPIO27 LOW)
//   0  -> MOSFET OFF (GPIO27 HIGH)
//   t  -> toggle
//   s  -> print current status
//   h  -> help
//
// For resistance measurement:
//   * Disconnect the external supply BEFORE measuring with an ohmmeter.
//     Ohms mode injects a small test voltage and only gives sensible
//     readings when no foreign voltage is present on the rail.
//   * Probe between MOSFET VOUT (+) and the load-side VOUT (-) / GND.
//   * Expected values:
//       ON  -> very low (typ. < 1 ohm, the FET's RDS_on)
//       OFF -> very high / OL (multimeter shows "open")

const uint8_t MOSFET_PIN = 27;
const bool MOSFET_ACTIVE_LOW = true;  // see header note

bool mosfetState = false;

void applyState() {
  // Active-low: ON -> pin LOW, OFF -> pin HIGH.
  bool pinHigh = MOSFET_ACTIVE_LOW ? !mosfetState : mosfetState;
  digitalWrite(MOSFET_PIN, pinHigh ? HIGH : LOW);
  Serial.print("MOSFET ");
  Serial.print(mosfetState ? "ON " : "OFF");
  Serial.print("  (GPIO27 ");
  Serial.print(pinHigh ? "HIGH" : "LOW");
  Serial.println(")");
}

void printHelp() {
  Serial.println();
  Serial.println("Commands:");
  Serial.println("  1 -> MOSFET ON");
  Serial.println("  0 -> MOSFET OFF");
  Serial.println("  t -> toggle");
  Serial.println("  s -> status");
  Serial.println("  h -> help");
}

void setup() {
  // Idle level = MOSFET OFF. For active-low this is HIGH.
  uint8_t idleLevel = MOSFET_ACTIVE_LOW ? HIGH : LOW;

  // Write idle level first, then set to OUTPUT -> no boot glitch.
  digitalWrite(MOSFET_PIN, idleLevel);
  pinMode(MOSFET_PIN, OUTPUT);
  digitalWrite(MOSFET_PIN, idleLevel);

  Serial.begin(115200);
  delay(200);
  Serial.println("MOSFET manual test ready.");
  printHelp();
  applyState();
}

void loop() {
  if (!Serial.available()) {
    return;
  }

  int c = Serial.read();
  switch (c) {
    case '1':
      mosfetState = true;
      applyState();
      break;
    case '0':
      mosfetState = false;
      applyState();
      break;
    case 't':
    case 'T':
      mosfetState = !mosfetState;
      applyState();
      break;
    case 's':
    case 'S':
      applyState();
      break;
    case 'h':
    case 'H':
      printHelp();
      break;
    case '\r':
    case '\n':
    case ' ':
      // Ignore newlines, CR, spaces.
      break;
    default:
      Serial.print("Unknown command: ");
      Serial.println((char)c);
      printHelp();
      break;
  }
}

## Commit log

2026-04-29 Initial commit: ESP32 humidity controller
    Adafruit ESP32 Feather V2 sketches for SHT40-based humidity control via
    DFRobot Gravity MOSFET (active-low) driving a 5 V ultrasonic mister:
    - esp32_mosfet_test/ manual MOSFET serial-control test
    - esp32_sht40_test/ SHT40 read-out test
    - esp32_humidity_control/ automatic mode (hysteresis 78/80 % RH)
    - esp32_humidity_control_switch/ same plus toggle/slide switch on GPIO33
    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
2026-04-29 Translate all comments and docs to English
    Same code, same pin assignments, same behaviour - only the human-readable
    parts (file headers, inline comments, Serial output, wiring docs) are now
    in English instead of German.
2026-04-29 Add Dynamixel bus scanner tool
    Standalone Pi-side script: pings all IDs (1..253) on the U2D2 and
    reports which motors respond with their model numbers. Exits 0 when
    exactly one motor is detected (configurable via --expected) so the
    script also works as a smoke test for fresh single-motor setups.
    Defaults match the existing Quadruped wiring: /dev/ttyUSB0,
    1 000 000 baud, protocol 1.0 (RX-24F).
2026-04-29 Add gentle single-motor wobble test
    Pings the configured motor, reads its current position, parks the goal
    there before enabling torque, then nudges +/- ~30 ticks (~9 degrees on
    RX-24F) and returns to the start. Always releases torque on exit, even
    on exceptions, so the motor cannot stay stuck heating up.
    [single_motor_test.py]
2026-05-10 Reorganize repo into humidifier/ and quadruped/ subsystems
    Group ESP32 humidity firmware under software/humidifier/ and Raspberry Pi
    gait control under software/quadruped/. Update setup_pi.sh, .gitignore, and
    README to reflect the new layout, and rewrite the README to cover both
    subsystems.
2026-05-10 Add course documents under docs/
    Adds reports, presentations, state diagrams, CAD models (.stl/.step/.stp),
    labeled renders, Pugh matrix, and component list to docs/, organized by
    type. Videos and the team archive ZIP are excluded (exceed GitHub's
    per-file size limit).
    [102 B Team 22 Pugh Matrix.xlsx, Battery-Holder.stp, Controller_Holder.stl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]
2026-05-11 Add master ESP32 Feather V2 wiring map
    Single-page reference that consolidates pin usage across all four
    sketches: which pin does what, which sketch uses which pins, how the
    shared 3V and GND rails distribute, and the rules for the external
    mister supply (common ground requirement).
    Per-sketch detail docs (wiring_humidity_control[_switch].md) stay
    unchanged; this is the at-a-glance summary you reach for first.
2026-05-14 Add one-paragraph robot assembly overview
    Top-level ASSEMBLY.md describes how the mechanical frame, the
    Dynamixel locomotion block, and the ESP32-based humidity-control
    subsystem come together into the running robot, including the common-
    ground requirement between the two power supplies.
2026-05-14 Expand ASSEMBLY.md with full BOM and per-subsystem build steps
    Replaces the single-paragraph overview with a structured build guide:
    component table for Lower and Upper parts, mechanical assembly of
    chassis/legs/bearings/motors, on-board electronics shelf with battery
    power path (12 V battery -> BEC -> Pi), Upper-Part tank/mister/sensor
    wiring, the M2.5 standoff stack-up that joins the two parts, and the
    common-ground bond between the two supplies. Closes with a three-step
    bring-up sequence that mirrors the test sketches already in the repo.
2026-05-14 Add colorless ESP32 pinout quick reference
    software/esp32_pinout.md: minimal table of which Feather V2 pin
    connects to what (no wire colors), plus the external mister-supply
    routing. Complements wiring_map_esp32.md for when you only need the
    final pin assignments at a glance.
